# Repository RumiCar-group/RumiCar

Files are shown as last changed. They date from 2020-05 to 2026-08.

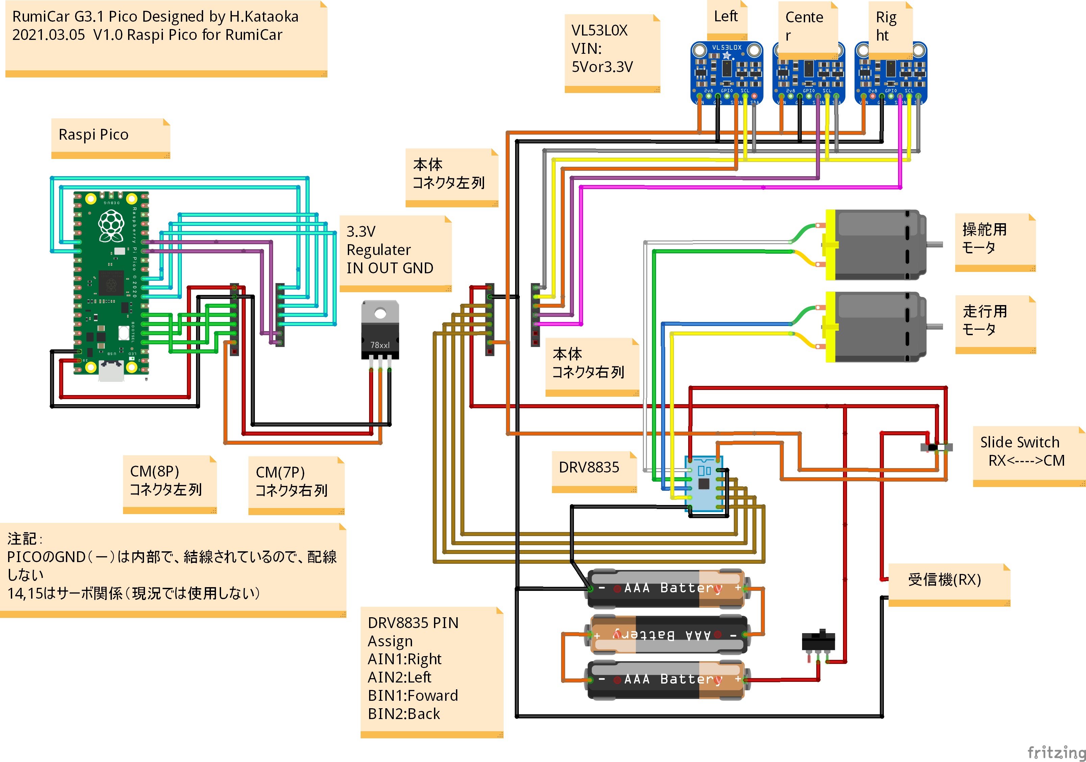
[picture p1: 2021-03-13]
CM PCB/Kataoka san CM/RasPi/結線図RasPiPICO.jpg

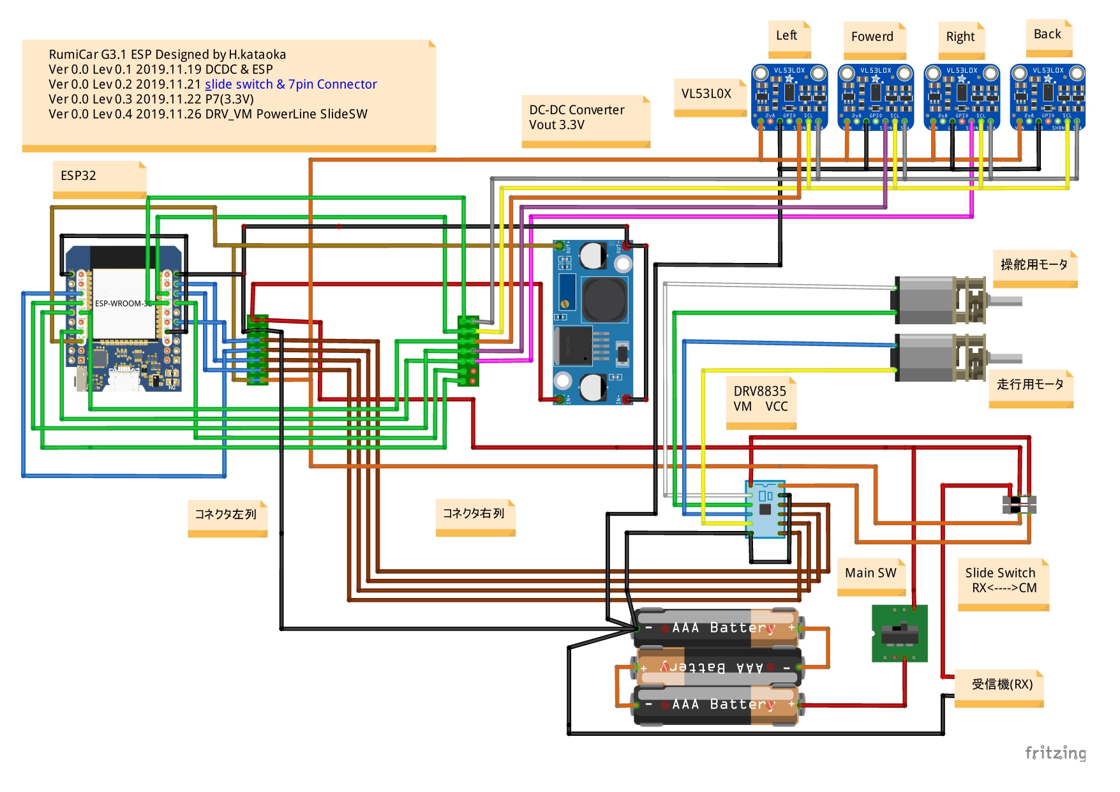
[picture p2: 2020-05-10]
開発用資料/結線図/結線図RumiCarG3.1_ESP32.jpg

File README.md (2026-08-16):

RumiCarロゴ
RumiCar写真

# RumiCar

> [!IMPORTANT]
> ## 📢 お知らせ / Announcement
>
> **Arduino IDE用のRumiCarライブラリは、Arduino公式のLibrary Managerに登録されました。**
>
> インストール手順（Arduino IDE 内で完結します）:
>
> 1. Arduino IDEのメニューから「スケッチ」→「ライブラリをインクルード」→「ライブラリを管理...」を開く
> 2. 検索ボックスに `RumiCar` と入力
> 3. 表示された `RumiCar` を選び「インストール」をクリック
> 4. 依存ライブラリ（VL53L0X）のインストール確認が表示されたら「Install all」を選択
>
> ライブラリのソースコード（参考）: [RumiCar-group/RumiCar-lib](https://github.com/RumiCar-group/RumiCar-lib)
>
> このリポジトリ内にあった `ArduinoAndESP32/Libraries/` 配下の旧ライブラリ（`.zip` と `RumiCar/` フォルダ）は**削除しました**。古い資料に残る「RumiCar.zip を選択」という手順はもう使えません。上記の Library Manager をご利用ください。
>
> ---
>
> **The RumiCar Arduino library has been published to the Arduino Library Manager.**
>
> Installation steps (all done inside Arduino IDE):
>
> 1. Open **Sketch → Include Library → Manage Libraries...** in Arduino IDE
> 2. Type `RumiCar` in the search box
> 3. Click **Install** on the `RumiCar` entry
> 4. When prompted to install the dependency (VL53L0X), choose **Install all**
>
> Library source code (for reference): [RumiCar-group/RumiCar-lib](https://github.com/RumiCar-group/RumiCar-lib)
>
> The local copy that used to be under `ArduinoAndESP32/Libraries/` **has been removed**. Older materials may still say "select RumiCar.zip" — that procedure no longer works; please use the Library Manager above.

**日本語** | [English (README.en.md)](README.en.md)

コンピュータモジュールの種類によりプログラムや使用コンピュータ言語が異なります。
Arduino Nano と ESP32 の場合はフォルダArduinoAndESP32をお使いください。
Raspberry Pi Zero W の場合はフォルダRasPiをお使いください。Raspiはコンピュータ言語はPythonです。

画像はYouTubeへのリンクです。クリックしてご覧ください。

- [RumiCar紹介動画](https://youtu.be/DxaY2eCzJzo)
- [衝突回避](https://youtu.be/95pc_4Wf14U)
- [Part 2 of 2 RumiCar on test course](https://youtu.be/oHujTh9AwAw)
- [車載カメラ視点](https://youtu.be/16kOgLMo-Tg)

RumiCar紹介動画 (https://www.youtube.com/watch?v=DxaY2eCzJzo "RumiCar紹介動画")
RumiCar衝突回避動画 (https://youtu.be/95pc_4Wf14U "RumiCar衝突回避動画")
RumiCarテスト走行動画 (https://www.youtube.com/watch?v=oHujTh9AwAw "RumiCarテスト走行動画")
RumiCar車載カメラ視点動画 (https://www.youtube.com/watch?v=16kOgLMo-Tg "RumiCar車載カメラ視点動画")
### 関連リポジトリ（RumiCar ファミリー）

<!-- AUTO-REPOS-JA:START -->
<!-- この表は自動生成です。手で編集しないでください(毎日、公開リポジトリ一覧から再生成されます)。
     説明文・表示順の変更は .github リポジトリの profile/repos-meta.json を編集してください。
     This table is auto-generated daily from the org's public repositories.
     Edit profile/repos-meta.json in the .github repository to change descriptions/order. -->
| リポジトリ | 内容 | ★ |
|---|---|---|
| [**RumiCar**](https://github.com/RumiCar-group/RumiCar) | 本体。サンプルプログラム、ハンズオン教材(PDF)、結線図、開発資料、シミュレータ用プログラム/コース | 35 |
| [**RumiCar-Simulator**](https://github.com/RumiCar-group/RumiCar-Simulator) | ブラウザで動く自動運転シミュレータ(インストール不要・実機互換) | - |
| [**RumiCar-PhotoStrip**](https://github.com/RumiCar-group/RumiCar-PhotoStrip) | 通信量にやさしい写真ストリップ(どのサイトでも使える汎用Web部品・MIT) | - |
| [**RumiCar-VideoLoop**](https://github.com/RumiCar-group/RumiCar-VideoLoop) | 動画ダイジェスト小窓(無音ティーザーをランダム連続再生・クリックで本編へ・MIT) | - |
| [**RumiCarRos**](https://github.com/RumiCar-group/RumiCarRos) | ROS 2対応の実装 | 3 |
| [**RumiCar-lib**](https://github.com/RumiCar-group/RumiCar-lib) | Arduinoライブラリのソースコード(導入はArduino IDEのライブラリマネージャから。ここからのダウンロードは不要) | - |
| [**RumiCar-AutoPost-Guide**](https://github.com/RumiCar-group/RumiCar-AutoPost-Guide) | Publish a WordPress post; What's New and the Facebook Page update automatically. A bilingual methods guide (ja/en) — setup, pitfalls, and log-based verification. | - |
| [**RumiCar-ReleaseNotes-Guide**](https://github.com/RumiCar-group/RumiCar-ReleaseNotes-Guide) | Publish a GitHub Release, get paired JA/EN WordPress articles automatically — a methods guide with the reference implementation from rumicar.com | - |
| [**RumiCarEX**](https://github.com/RumiCar-group/RumiCarEX) | 関連プロジェクトのfork(派生車体) | - |
| [**micro-airc**](https://github.com/RumiCar-group/micro-airc) | 関連プロジェクトのfork(AI RCカー) | 1 |
| [**rumicar-duck**](https://github.com/RumiCar-group/rumicar-duck) | 関連プロジェクトのfork(アヒル型走行車) | - |
<!-- AUTO-REPOS-JA:END -->

### フォルダの説明

- [**ArduinoAndESP32**](https://github.com/RumiCar-group/RumiCar/tree/master/ArduinoAndESP32)フォルダ<br>RumiCarのコンピュータモジュール(CM)のArduino Nano版とESP32版用のサンプルプルプグラムです。<br>ハンズオンで使用するプログラムが保存されています。RumiCarハンズ用の資料は[**ハンズオン用テキスト**](https://github.com/RumiCar-group/RumiCar/tree/master/%E3%83%8F%E3%83%B3%E3%82%BA%E3%82%AA%E3%83%B3%E7%94%A8%E3%83%86%E3%82%AD%E3%82%B9%E3%83%88)フォルダの下に保存されていますのでまずそちらを参照ください。

  - **Exercise-1 距離を測ってみよう！**<br>RumiCarには車体の前方に3個のレーザー測距モジュールを搭載しています。レーザー測距モジュールは人体に無害のレーザー光線を対象物に当て、その反射光が戻ってくるまでの***時間***を計測することによって距離を測定します。音速はマッハと呼ばれ時速1000km以上の速度ですが、光の速さはその音速の***88万倍***も速いです。その光が反射して返ってくるまでのとても短い時間を計って距離を計測するなんて凄いですね。
  
    - **Exercise-1.1 中央のセンサで測距しよう！**<br>RumiCarに3個搭載されているレーザー測距モジュールのうちの一つ、中央のセンサーを使って距離を測ってみます。Arduino IDEが持っているシリアルモニタの機能を使い、測定した距離を皆さんのパソコンにリアルタイムで表示します。センサの前に手をかざして手を前後に動かすと、手とセンサの間の距離が変わりますのでシリアルモニタに表示される距離の値もリアルタイムで変化します。
    - **Exercise-1.2 3つのセンサで測距だ！**<br>RumiCarに搭載されている3個のセンサを全部同時に動かしてみましょう。左、中央、右のそれぞれのセンサが測定した距離の値を同時にリアルタイムでパソコンの画面に表示します。
    - **Exercise-1.3 シリアルプロッタを使ってみよう**<br>Arduino IDEにはシリアルプロッタの機能もあります。これはデータを自動でグラフ表示してくれる機能です。プログラムはExercise-1.2と同じものを使いますが測定した距離値がリアルタイムに色分けされてグラフ化表示されます。Exercise-1.2と同じようにセンサの前に手をかざしてグラフが変化するか見てみましょう。どの色のグラフがどのセンサの値を表示しているか確かめましょう。このExerciseではExercise-1.2のプログラムをそのまま使いますので専用のプログラムはありません。
  - **Exercise-2 モータ制御**<br>RumiCarはハンドルを曲げる時と走行する時にモータを使います。RumiCarではCMのコンピュータがプログラムに従って、ハンドルを動かしたりRumiCarが走るためにタイヤを回転させたりします。コンピュータモジュールを使ってRumiCarのモータを動かしてみましょう。
    - **Exercise-2.1 ハンドルを切る**<br>RumiCarの前のタイヤを左右に動かしてみましょう。このプログラムではハンドルを左右に切ってそのまま0.5秒保持します。その動作を繰り返します。つまり、左に切って0.5秒、右に切って0.5秒、また左に切って0.5秒と、ずっと繰り返します。
    - **Exercise-2.2 速度制御**<br>RumiCarの走る速度をコントロールしてみましょう。コンピュータモジュールからの命令によって走行用車輪、すなわち後ろのタイヤを回転させます。タイヤの回転速度を変化させることによりRumiCarの走るスピードを変化させることができます。ここではプログラムを使ってタイヤの回転速度を段階的に変化させます。モータの回転音が変わりますのでタイヤの回転を見るのと同時にモータの音の変化にも気をつけてみてください。
    - **Exercise-2.3 前進と後進**<br>実際の自動車は前に進んだり後ろに下がったりします。RumiCarも同様に前進や後進ができます。プログラムを使ってRumiCarを前進させたり後進させてみましょう。RumiCarを走らせる場所が無い時は、RumiCarを手にしっかり持って後ろのタイヤが前進方向に回転したり、後進方向に回転するのを確認しましょう。
    - **Exercise-2.4 ジグザグ走行**<br>RumiCarをジグザグに走行させてみましょう。ハンドルを左右に切りながら前進します。RumiCarを走らせられる場所が無い場合はRumiCarをしっかり手に持って期待通りの動きになっていることを確認しましょう。
  - **Exercise-3 自律走行基礎**<br>自律走行の基礎としてセンサ等が取得した情報を元に判断してRumiCarを制御してみます。前方の障害物や左右の壁などの距離を測定し、停止したり左右にハンドルを切りながらRumiCarを走行させてみます。
    - **Exercise-3.1 安全に停止する車**<br>前方に障害物を発見して安全に停止する車を考えます。RumiCarが直進中に前方に障害物を発見したら停止し、障害物が無くなったら走行そ再開します。障害物が近づいてきたら、安全のために後進します。あなたの手を障害物と仮定してRumiCarがあなたの手にぶつからずに停止するか試してみましょう。RumiCarが停止中にあなたの手をRumiCarに近づけたら安全確保のためにRumiCarが後進しますか？
    - **Exercise-3.2 市街地を走る車**<br>このExerciseでは実際に走行コースを設置してRumiCarを走らせます。左右の壁や前方の障害物を検知しながらRumiCarが走行します。
- **[ESP32](https://github.com/RumiCar-group/RumiCar/tree/master/ESP32)フォルダ**<br>RumiCarのCMのうち、ESP32はWiFiやBluetoothなどの通信機能を内蔵しています。ここではESP32のBluetooth機能を使ってRumiCarのセンサ測距値を無線で取得して表示させたり、RumiCarをワイヤレスで制御するサンプルプログラムが入っています。
     - **BLEフォルダ**<BR>Bluetooth Low Energy(BLE)での通信。RumiCarのESP32版CMに搭載されているBLEを使ってスマホ(iPhone)と通信してみましょう。3個の測距モジュールでの距離計測値をiPhoneのBLE Scannerとのアプリで表示させています。マルチコネクトが可能なので、個別の機器と接続や切断が不要ですので、一度に複数の機器から1台のRumiCarに接続することができます。展示会などで来場者に各自のスマホからRumiCarに接続してもらい、自分のスマホで計測値を表示させて楽しんでいただくことなどが可能です。
    - **Bluetoothフォルダ**<br>Exercise-1.2はRumiCar ESP32版CM用Bluetoothシリアル通信のサンプルプログラムです。RumiCarをWindows PCとBluetoothで接続してRumiCarのレーザー測距モジュールの測定距離値をパソコンに表示したり、パソコンからコマンドを送ってRumiCarを操作することができます。
      - Windos10とペアリング
      - 設定->デバイス->Bluetoothとその他のデバイス->Bluetoothまたはその他のデバイスを追加する->Bluetooth
      - RumiCar_ESP32を選択
      - デバイスマネージャー->ポート(COMとLPT)で"Bluetooth リンク経由の標準シリアル(COM #)"　を確認する。 #は数字です。　(2個表示される)
      - Arduino IDEの設定でツール->シリアルポート　で、上記COM #に合わせる
      - ESP32が「ケーブルを繋いでいない」のに測距値がシリアルモニタに表示できます。
      - PC側からコマンドを送ってRumiCarをコントロールできます。
      - サンプルプログラムはコマンド「r」、「l」、「f」、「b」に対応しています。それぞれ右、左、前進、後進を0.5秒実行します。コマンドは全て小文字です。 Arduino IDEのシリアルモニタの送信でコマンドを送ります。
      - ケーブル接続が不要なので、走行中に実際の測距データをPC側で取得したり、PC側からコマンドを送ってラジコンのような操作をすることができるようになります。

- **[RasPi](https://github.com/RumiCar-group/RumiCar/tree/master/RasPi)フォルダ**<br>RumiCarのコンピュータモジュールのラズパイ版のサンプルプログラムです。Pythonで記述されています。ラズパイ版CMを使ってRumiCarを動かす場合にお使いください。
  - **Exercise-1 距離を測ってみよう！**
    - **Exercise-1.1 中央のセンサで測距しよう！**
    - **Exercise-1.2 3つのセンサで測距だ！**   
  - **Exercise-2 モータ制御**   
    - **Exercise-2.1 ハンドルを切る**    
    - **Exercise-2.2 速度制御**
    - **Exercise-2.3 前進と後進**
    - **Exercise-2.4 ジグザグ走行**  
   - **Exercise-3 自律走行基礎**
     - **Exercise-3.1 安全に停止する車**   
     - **Exercise-3.2 市街地を走る車**
 - **[ハンズオン用テキスト](https://github.com/RumiCar-group/RumiCar/tree/master/%E3%83%8F%E3%83%B3%E3%82%BA%E3%82%AA%E3%83%B3%E7%94%A8%E3%83%86%E3%82%AD%E3%82%B9%E3%83%88)フォルダ**<br>RumiCarのハンズオン用テキストが保存されているフォルダです。RumiCarの歴史や仕組み、サンプルプログラムを使ってRumiCarを動作させる方法や例が載っています。ハンズオン用テキストはPDF形式で約10MBほどのファイルサイズです。GitHubから直接参照しようとすると表示できないことがあるようです。一旦ダウンロードしていただいてからご覧ください。
- **[教育機関向け追加課題](https://github.com/RumiCar-group/RumiCar/tree/master/%E6%95%99%E8%82%B2%E6%A9%9F%E9%96%A2%E5%90%91%E3%81%91%E8%BF%BD%E5%8A%A0%E8%AA%B2%E9%A1%8C)フォルダ**<br>RumiCarを教材として教育機関にて授業や演習で利用する場合の追加課題です。Rumicarハンズオンの資料はRumiCarの仕組みや構成を学べるように作られています。学生が自ら更に深く考えて課題を克服し、より良いアルゴリズムを開発できるように研究課題の基礎やグループワークに使えるように追加の課題をまとめました。是非ご利用ください。
- **[開発用資料](https://github.com/RumiCar-group/RumiCar/tree/master/%E9%96%8B%E7%99%BA%E7%94%A8%E8%B3%87%E6%96%99)フォルダ**<br>RumiCarの車体やCMを自作する場合の開発用資料です。

  1. RumiCarを自作する場合はまず「RumiCarの作り方」をご覧いただき、RumiCarを作製後、作製したCMとRumiCarが正しく動作できているかの確認のために、「RumiCarの動作確認方法」の内容に従ってご確認ください。是非多くの人たちにオリジナルのRumiCarを作製いただき、RumiCarの世界を楽しんで頂けると嬉しいです<br>1.1 CMの作製においてArduino Nano以外のCM作製のための情報を追加しました。<br>1.2 ステアリングをサーボ化する場合のピンアサイン(13番ピン)を追加しました。
  1. RumiCarを受け取ったり、運送等により故障していないかを確認する場合は「RumiCarの動作確認方法」の内容に従ってRumiCarが正常動作するかご確認ください。
  1. 各CM別のピンアサイン表があります。プログラムの互換性確保のためCMを自作する場合の結線はそれに従ってください。<br>
  - **結線図フォルダ**
    - 結線図(ArduinoNano).jpg<br>RumiCarの基本である、Arduino Nano版CMの結線図です。RumiCarをこれから始める人向け。
    - 結線図(Raspberry Pi Zero W).png<br>ラズパイZero W版CMの結線図です。Pythonを使いたい方、画像認識、AI等挑戦されたい方向け(上級者向け)。
    - 結線図RumiCarG3.1_ESP32.jpg<br>ESP32版CM結線図です。WiFiやBluetooth接続、ニューラルネットワーク(NN)プログラム等に挑戦されたい方向け(上級者向け)。
    - 車体接続結線表.jpg<br>RumiCar車体側の結線図です。車体を自作されたい方は、このインターフェイスに合わせて作製ください。
    - ピンアサインArduino-ESP32-RasPi-Obniz<br>Rumicar車体のインターフェイスと、各CMのArduino nano、ESP32、ラズパイ、Obnizのピンアサインを一つの表にまとめたものです。
  - **RumiCarの作り方**<br>RumiCar車体の開発方法や各種CMの作製方法が掲載されています。RumiCarの自作を考えられている方は、この資料を参考に是非オリジナルのRumiCarを作製してみてください。作製したRumiCarは「RumiCarの動作確認方法.pdf」の内容に従って動作確認ができます。   
  - **RumiCarの動作確認方法**<br>RumiCarを新規に作製した場合や、運送などにより故障が発生していないか、のためにRumiCarが正常に動作するか確認するための手順をまとめた資料です。こちらを参考にRumiCarの動作確認をしましょう。

- **RumiCar Simulator(ブラウザ版シミュレータ)**<br>ブラウザ上で RumiCar の走行プログラムを書いて試せるシミュレータです → [**RumiCar Simulator**](https://www.rumicar.com/simulator/)。実機が無くてもプログラムの動作を確認でき、車種(FF/FR/4WD × ノーマル/ドリフト)ごとの挙動の違いも体験できます。ここで作った Arduino C++ のプログラムは**そのまま実機 RumiCar でも動作**します。ソースコードは [**RumiCar-group/RumiCar-Simulator**](https://github.com/RumiCar-group/RumiCar-Simulator) で公開しています(自分のサーバーで動かす手順も同梱)。
  - **[programs](https://github.com/RumiCar-group/RumiCar/tree/master/programs)フォルダ**<br>シミュレータ用の走行プログラム集です。車種別に最適化した「Fable Racing Line」6種と、その**設計思想・各定数の意味・実車でのチューニング手順**を [programs/README.md](https://github.com/RumiCar-group/RumiCar/tree/master/programs) に解説しています(各 .ino の冒頭にも「なぜこの設定にしたか」を記載)。利用者が改変したプログラムは [programs/community](https://github.com/RumiCar-group/RumiCar/tree/master/programs/community) に別名で投稿でき(プルリクエスト方式)、シミュレータの「🌐 みんなの投稿」から誰でも再利用できます。
  - **[courses](https://github.com/RumiCar-group/RumiCar/tree/master/courses)フォルダ**<br>シミュレータ用のコースデータです。30種のテストコースと、利用者が投稿したコース([courses/community](https://github.com/RumiCar-group/RumiCar/tree/master/courses/community))が入っています。投稿方法は [courses/README.md](https://github.com/RumiCar-group/RumiCar/tree/master/courses) を参照してください。

### ハードウェア構成

RumiCar 車体は、車体前部に **3 基のレーザー測距（ToF）モジュール**（左・中央・右）を搭載し、その測定値をコンピュータモジュール（CM）が処理して、ステアリングと走行モータを制御します。CM は USB ケーブルで PC に接続してプログラムを書き込みます。

CM は用途に応じて複数の選択肢があります。

| CM | 言語 | 主な用途 |
|---|---|---|
| **Arduino Nano** | C++ | 基本構成。これから始める方向け |
| **ESP32** | C++ | Wi-Fi / Bluetooth・BLE 連携、ニューラルネットワーク等（上級者向け） |
| **Raspberry Pi Zero W** | Python | 画像認識・AI 等（上級者向け） |
| **Obniz** | — | ピンアサイン表に対応表を掲載 |

結線図・ピンアサイン表・「RumiCar の作り方」「RumiCar の動作確認方法」は、上の「フォルダの説明」にある[開発用資料フォルダ](https://github.com/RumiCar-group/RumiCar/tree/master/%E9%96%8B%E7%99%BA%E7%94%A8%E8%B3%87%E6%96%99)にあります。自作される場合は、プログラムの互換性確保のため、ピンアサイン表に従って結線してください。

### 参加する（協力者募集）

RumiCar は有志で開発しています。**一緒に RumiCar したい方・企業を募集しています。**

- ソフトウェア（自動運転アルゴリズム、IDE、画像認識、Autoware 導入）
- ハードウェア（車体開発・量産、CM 開発、PCB 設計）
- Website 編集・管理（WordPress）、技術アドバイザー
- 広報（YouTube 動画編集、イベント告知）、イベント運営、資金調達

貢献可能な分野とモチベーションを添えて **info@RumiCar.com** までご連絡ください。各国での開発・教室・トレーニング・カンファレンス開催も計画しており、各国拠点でご協力いただける方を探しています。

  ### その他大事なこと
  - [**RumiCar website**](https://www.rumicar.com)<br>RumiCarのwebisteです。今後このwebisteを発展させたいので、websiteの編集をしてくださる方は是非ご連絡ください!
  - [**RumiCar YouTube**](https://www.youtube.com/channel/UCVg3CBSVBcc_00FdC6q2wDg)<br>RumiCarのYouTubeチャンネルです。RumiCarの紹介動画や各種走行動画、開発途中の各種テストの動画などがアップロードされています。是非チャンネル登録をお願いします。また、動画編集をしてくださる方も是非ご連絡ください。
  - [**RumiCar group**](https://www.facebook.com/groups/rumicar)<br>RumiCarのFaceBookグループです。皆様のご参加をお待ちしてます。
  - [**connpass**](https://rumicar.connpass.com)<br>RumiCarの走行会や開発教室、オンラインセミナーなどイベント告知や参加者募集のページです。RumiCarイベントに参加ご希望の方は是非メンバー登録をお願いいたします。
  - [**RumiCarハンズオン中継の録画**](https://youtu.be/99zH73B8NUo)<br>ALGYANとコラボしたRumiCarイベントのアーカイブです。イベント内でExerciseの解説やデモをしています。

Issue・プルリクエストは**英語でも日本語でも歓迎**します。 / Issues and pull requests are welcome in English or Japanese.

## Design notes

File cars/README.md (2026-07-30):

# cars — 車種カタログ

- `cars/community/*.json` — **利用者が投稿した独自車種** (車種 def 形式)

[RumiCar Simulator](https://www.rumicar.com/simulator/) は起動時に `cars/community/` を読み込み、
車種の選択肢に **「🌐 名前」** として追加します。誰でも選んで走らせ、再利用できます。

組込の6車種 (ノーマル FR/FF/4WD・ドリフト FR/FF/4WD) はシミュレータ本体に入っており、
ここには含まれません。このフォルダは**投稿されたものだけ**が入ります。

## 車種を投稿する (PR)

1. シミュレータの「車種」パネルで「車種を追加」を開き、フォームまたは JSON でパラメータを決める
2. 走らせて納得いくまで調整する
3. 「🌐 共有」ボタンを押す → GitHub の新規ファイル作成画面が JSON 入りで開きます
4. そのままコミットするとプルリクエストが作成されます (書込権限が無い場合は自動で fork されます)
5. マージ後、全利用者の車種一覧に表示されます

## フォーマット

`key` と `name` が必須で、あとは省略すると**ノーマル FR の値で埋まります**。一部だけ指定しても動きます。

```json
{
  "key": "custom_lightweight_fr",
  "name": "軽量ライトウェイトFR (投稿例)",
  "mass": 900,
  "accel": 1.18,
  "os": 0.12,
  "powerOs": 0.34,
  "drift": null
}
```

実例は [`community/example-community-car.json`](community/example-community-car.json) にあります。

### パラメータ

| キー | 範囲 | 意味 |
|---|---|---|
| `mass` | 200〜3000 | 車重(kg)。重いほど旋回でアンダー(慣性)・制動が伸びる |
| `accel` | 0〜3 | 加速の倍率。大きいほど速く目標速度へ |
| `brake` | 0〜3 | 制動の倍率。大きいほど短く止まる |
| `maxSpeed` | 0〜2 | 最高速の倍率 (基準 0.7 m/s に対する比) |
| `spin` | 0〜2 | 発進ホイールスピン量。大きいほど発進で空転し加速が鈍る (FF大/4WD≈0) |
| `yawGain` | 0〜3 | 旋回ヨーの基本倍率 |
| `us` | 0〜2 | 定常アンダーステア量。大きいほど高速で曲がりにくい |
| `os` | 0〜2 | 定常オーバーステア量。大きいほど高速で巻き込む |
| `powerUs` | 0〜2 | アクセルON時に増すアンダー (FF: 前輪が駆動+操舵で飽和) |
| `powerOs` | 0〜2 | アクセルON時に増すオーバー (FR: パワーオーバーステア) |
| `liftOffOs` | 0〜2 | アクセルOFF旋回で増すオーバー (タックイン) |
| `brakeOs` | 0〜2 | 制動中に増すオーバー (前荷重でリアが軽い。FR顕著) |
| `slide` | 0〜1 | 通常時の横滑り量 |
| `drift` | — | ドリフト設定。`null` = 滑らない |

数値はすべて有限数である必要があります (`null` や `NaN` は不正)。範囲外の値は保存時に弾かれます。

### ドリフトさせる場合

`drift` にオブジェクトを与えると、省略した項目はドリフト FR の既定値で埋まります。

```json
{
  "key": "custom_drift_special",
  "name": "投稿ドリフト車",
  "drift": {
    "trigger": "power",
    "grip": 0.85,
    "gain": 6.0,
    "minSp": 0.20,
    "slipYaw": 1.10,
    "slipSlide": 0.90,
    "attack": 8.0,
    "release": 4.0,
    "brakeDrift": false
  }
}
```

| キー | 範囲 | 意味 |
|---|---|---|
| `trigger` | `"power"` / `"liftoff"` | 滑り出す契機。`power` = 踏み過ぎ (FR/4WD)、`liftoff` = 急に抜く (FF) |
| `grip` | 0〜1.5 | この駆動力を超えると滑り出す閾値 |
| `gain` | 0〜12 | 滑りの増え方 |
| `minSp` | 0〜2 | 滑り出しに要する最低速度 |
| `slipYaw` | 0〜3 | 滑走中に増える回頭量 |
| `slipSlide` | 0〜2 | 滑走中の横流れ量 |
| `attack` | 0〜20 | 滑り出しの速さ |
| `release` | 0〜20 | グリップ回復の速さ。大きいほど御しやすい |
| `brakeDrift` | 真偽値 | 制動でもドリフトを誘発するか |

## ルール (ゆるく)

- **上書きせず別名で**追加してください。`key` は組込6種 (`normal_fr` / `normal_ff` / `normal_awd` / `drift_fr` / `drift_ff` / `drift_awd`) と重複させないでください
- 不要になったファイルの**削除は GitHub 上**で行います
- 極端なパラメータ (異常に軽い・速い) は他の投稿と一緒に走らせたとき成立しなくなります。まずシミュレータで走らせて確認してください

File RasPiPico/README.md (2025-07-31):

# Raspberry Pi Pico
The build is using [Arduino-Pico](https://arduino-pico.readthedocs.io/en/latest/).

As name suggests, it allows executing Arduino code on Pico!

## Setup PIO
https://docs.platformio.org/en/latest/core/installation/methods/installer-script.html

## Build
```
pio run
```

## Build, Upload and Run
1. Press BOOTSEL
2. Connect USB
3. Unpress BOOTSEL
4. Run:
```
pio run -t upload
```

## Serial Output
```
pio device monitor
```

## Examples
Please, follow `../ArduinoAndESP32/`

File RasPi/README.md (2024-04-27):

# RumiCar
2020年4月25日(土)に開催された「RumiCarハンズオン中継！自動運転アルゴリズムを楽しく手軽に体感しよう！#2 」で使用されたExerciseのラズパイ版です。

## Setup

If you don't have RasPi monitor and keyboard, please check [Remote Access](docs/RemoteAccess.md).

### SMBus (I2C)
Used for VL53L0X.
```
sudo apt install python3-smbus
sudo raspi-config
# Interface Options -> I2C -> Yes
```

### GPIO
* [pigpio library](http://abyz.me.uk/rpi/pigpio/index.html) 使用
* [pinout](https://pinout.xyz/)

```
sudo apt-get update
sudo apt-get install pigpio python3-pigpio  # python-pigpio - python2 deprecated
sudo systemctl enable --now pigpiod
```

以下主要なGPIOをライブラリサイトより一部抜粋。

| PIN | Note  | GPIO |
| --- | ----- | ---- |
| 1 | 3V3 | |
| 2 | 5V | |
| 3 | SDA | 2 |
| 4 | 5V | |
| 5 | SCL | 3 |
| 6 | GND | |
| 9 | GND | |
| 11  | AIN1  | 17 |
| 12  | BIN1  | 18 |
| 13  | AIN2  | 27 |
| 14  | GND | |
| 15  | SERVO | 22 |
| 16  | SHDN0 | 23 |
| 17  | 3V3 | |
| 18  | SHDN1 | 24 |
| 20  | GND | |
| 22  | SHDN2 | 25 |
| 25  | GND | |
| 30  | GND | |
| 33  | BIN2  | 13 |
| 34  | GND | |
| 37  | SERVO | 26 |
| 39  | GND | |

## Exercises

```
cd ~/RasPi/Exercise-1.1
python Exercise-1.1.py

cd ~/RasPi/Exercise-1.2
python Exercise-1.2.py

# ...
```

## Video Streaming
To enable camera, edit `/boot/firmware/config.txt` (or `/boot/config.txt`):
```
camera_auto_detect=0
start_x=1
```

Check camera specs:
```
sudo apt install v4l-utils
v4l2-ctl --all
```

On robot:
```
sudo apt-get install gstreamer1.0-tools gstreamer1.0-plugins-good

gst-launch-1.0 v4l2src device=/dev/video0 ! video/x-raw, format=YUY2, width=640, height=480, framerate=30/1 ! jpegenc ! rtpjpegpay ! udpsink host=<ubuntu>.local port=1234
```
, where the `<ubuntu>` is hostname of your PC from the same LAN.

On PC:
```
gst-launch-1.0 -v udpsrc port=1234 ! "application/x-rtp, payload=26" ! rtpjpegdepay ! jpegdec ! autovideosink sync=false
```

General camera info:
* https://www.raspberrypi.com/documentation/accessories/camera.html

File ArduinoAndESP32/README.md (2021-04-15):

# Arduino Nano, ESP32版CM
画像はYouTubeへのリンクです。動画ではExerciseをデモンストレーションしています。クリックしてご覧ください。<br>
[YouTube video: 【オンライン開催】RumiCarハンズオン中継！自動運転アルゴリズムを楽しく手軽に体感しよう！](https://youtu.be/99zH73B8NUo)<br>
【オンライン開催】RumiCarハンズオン中継！自動運転アルゴリズムを楽しく手軽に体感しよう！ (http://www.youtube.com/watch?v=99zH73B8NUo)<br><br>
Arduino NanoおよびESP32のCMに対応したRumiCarのExercise集です。

Exercise, Exercise-1.1~3.2については、Arduino IDEのライブラリ設定が必要です。[導入方法](./Libraries/README.md)を参照してください。

Exercise-A2.3やExercise-A3.1など数字の後にAとBが付いているExerciseは上級編です。モーターをゆっくりと回転させたりスムーズに回転させる、難易度が少し高めのプログラムです。イベント中には使いませんが挑戦してみてください。

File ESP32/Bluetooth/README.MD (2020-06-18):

#　Exercise-1.2はRumiCar　ESP32版用Bluetoothシリアル通信のサンプルプログラムです

1. Windos10とペアリング
1.1 設定->デバイス->Bluetoothとその他のデバイス->Bluetoothまたはその他のデバイスを追加する->Bluetooth
1.2 RumiCar_ESP32を選択
1.3 デバイスマネージャー->ポート(COMとLPT)　　で　"Bluetooth リンク経由の標準シリアル(COMn)"　を確認する"n"は数字　(2個表示される)
1.4 Arduino IDEの設定でツール->シリアルポート:　で、上記COMnに合わせる

２.ESP32が「ケーブルをつないでいない」のに測距値がシリアルモニタに表示できます

３.PC側からコマンドを送ってRumiCarをコントロールできます

サンプルプログラムはコマンド「r」、「l」、「f」、「b」に対応、それぞれ右、左、前進、後進を0.5秒実行します。コマンドは全て小文字です。
Arduino IDEのシリアルモニタの送信でコマンドを送ります

ケーブル接続が不要になりますので走行中に実際の測距データをPC側で取得したりPC側からコマンドを送ってラジコンのように操作したり、ができるようになります

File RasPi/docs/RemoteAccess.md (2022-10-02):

# Remote Access

allows using RumiCar without monitor and keyboard.

## Change WiFi with Command Line
This step is needed if Wifi does not work. 

### Easy Way
* Just run RasPi Imager again setting other WiFi.

### Hard Way
[**RasPi Config**](https://www.raspberrypi.com/documentation/computers/configuration.html#using-the-command-line)
* Insert SD card into other linux PC.
* Edit `<SD card mount>/etc/wpa_supplicant/wpa_supplicant.conf`
* Insert SD card back, start the RasPi and check it is connected to WiFi.

### Notes
* The RasPi needs to be in the same LAN as your remote PC. For example, both PC has address `192.168.1.* / 24`.
* Sometimes WiFi can isolate PC from each other, so in this case either disable the isolation or use another WiFi.

## ssh
```
# Remote PC
ssh pi@rcar.local  # <user>@<host>.local
```
On windows, [**Bonjour**](https://support.apple.com/kb/dl999) is needed to use `.local` hostname instead of ip address.

## Copy Sources
```
# Remote PC
scp -r RasPi pi@rcar.local:
```

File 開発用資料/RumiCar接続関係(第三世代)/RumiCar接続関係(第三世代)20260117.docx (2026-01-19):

RumiCarインターフェイス資料（第三世代）

2026年1月17日版

表目次

図目次

# 1. 定義・参考情報

  (1) 電線
    1 電力系　AWG24（最大3.5A）程度
    2 信号系　~~AWG30（最大0.86A）程度~~マルツではAWG28までしか売ってない。AWG28(最大1.2A)
  (2) 電源
    1 車体から供給される電源は基本4.5Vと仮定されて仕様が決められている。これ以外の電圧の車体で利用する場合はCM側の電圧昇降圧機能を鑑みて運用を考えること
  (3) CM
    1 コンピュータモジュールの略。ArduinoやESP32が搭載されRumiCarと接続して使われる

# 2. 注意

(1) DRV8835の信号線はDRV8835のVCCが上限になる。信号線接続時は接続コンピュータの信号最大値に気を付けること
(2) VL53L0Xの信号最大電圧及びI2C信号電圧にも気を付けること。基本的にVL53L0XのVCCと合わせる。
(3) Arduino系のPWMピンは3,5,6,9,10,11の６本。タイマ0のみが960Hz、Servoライブライを使うとタイマ1（9,10番ピン）のPWMは使えなくなる。これより操舵を3,11番(タイマ2)、走行を5,6番(タイマ0)、サーボを9,10番(タイマ1)とするのが良いだろう。

表 　ArduinoタイマとPWM

タイマ | ピン | 周波数
タイマ0 | ５、６ | 980Hz
タイマ１ | ９、１０ | 490Hz
タイマ２ | ３、１１ | 490Hz

(4) Arduino NanoはツールメニューからプロセッサとしてATmega328p(Old　bootloader)を指定すること。そうしないと書き込めない（2018年11月26日追記）

# 3. 接続

(1) 車体インターフェイス表記:Pnn 例:P10はSHDN0の意味
(2) A-D9等はArduinoのディジタル9番ピンの意味。E-xxx表記はESP32のピンの意味
(3) VL53L0X(レーザー測距モジュール)
1 1モジュール当たりに電源２本、I2C ２本とアドレス設定用１本（SHDN）が必要、つまり1モジュール当たり5本、ただし電源と信号線2本は共通で良い
2 3モジュールの場合は電源2本、I2C 2本、SHDNモジュール数分(3本)の7本必要
3 動作電圧は3.3Vから5.0V、自動車本体は4.5V供給可能であるが信号線最大電圧に合わせる必要があるのでP7(Arduino　V5、ESP３２　3.3V)から電源供給することにする
(4) UART(シリアル通信)
1 Arduino

ハードウエアシリアルは１個しかない。通常その１個はPCでのシリアルモニタに使う。そのため他のモジュール(例えばVR3等)とシリアル通信をする場合はソフトシリアルを使う。シリアル通信用ピンは空いているピンをソフトウエア的に設定可能。例えばA6、A7やD7、D8などが使える。もちろんシリアルモニタを使わない、PCと接続しない使い方であればシリアル0が使える。

2 ESP32

ハードウエアシリアルは３個ある。シリアル0はPCと接続、シリアルモニタで使う。シリアル1は内部使用のため使えない。従ってシリアル2を使う。ピンはGPIO16と17を使う。

表 1　ESP32のUART

UART | RX | TX | 備考
UART0 | GPIO3 | GPIO1 | USB書き込みで使用、使用推奨しない
UART1 | GPIO9 | GPIO10 | 通常使用不可
UART2 | GPIO16 | GPIO17 | 今回採用

(5) 電源の考え方

ArduinoはUSB経由での電源供給は5Vになる。仕様では７Vから12VをVINに供給することになっている。ArduinoはVINの電源から内蔵レギュレータにより自分で内部電源用5Vを生成している。現在Arduino系CMの電源には昇圧型可変電圧型DC-DCコンバータ(MT3608等)を使っている。可変電圧型DC-DCコンバータで正確に3.3Vや5Vを生成しにくいため仕様に従ってVINに7.2V程度を供給している。DRV8835やVL53L0Xの電源供給はArduinoの供給能に頼っている。Arduinoは1ピン当たり最大40mAで全体で100mA供給できる。ESP32は供給可能な電力がもっと少ないのでESP32などから電源供給させずに3.3V固定型DC-DCコンバータなどを使いESP32への電源供給とともにP7(DRV8835やVL53L0Xへの電源供給ピン)へも並列で電源供給すると良いだろう。電圧固定型DC-DCコンバータであれば例えば5V供給するのであればArduinoもVINではなく5Vラインに直接電源供給できる。

(6) I2C通信

通常I2C通信の機器は機器毎に固有のアドレスを持たせてそのアドレスに対して通信する。逆に言うと複数の機器を同時に使う場合、それらの機器のアドレスは重複せずに一意である必要がある。今回VL53L0Xを複数使うがVL53L0Xは工場出荷時に全てに同じアドレスが設定されている。複数使うときにはアドレスの再設定が必要となる。VL53L0Xの仕様としてSHDN(シャットダウン)後にアドレスを送るとその機器のアドレスがその送ったアドレスに書き換わる機能がある。今回その機能を使って3個のVL53L0Xを使い分けることにした。書き換えられた新アドレスは機器に記憶されないのでVL53L0X起動時に常にCMから各VL53L0Xのアドレスを書き換えて使用するロジックを組む必要がある。

(7) CMモジュール(Arduino等側)と車体側の接続
1 EX-IF（車体インターフェイス(車体側、図の上方が進行方向(前方))）

表 2　第三世代　車体-CM接続インターフェイス(EX-IF)(旧表記)

I/O | 用途 | ピン番号 | | 用途 | I/O
O | 電源(4.5V) | 1 | 8 | SDA:E-GPIO21 | I
O | GND | 2 | 9 | SCL:E-GPIO22 | I
I | AIN1:右折側:A3; E-GPIO04 | 3 | 10 | SHDN0(左):E-GPIO19 | I
I | AIN2:左折側:A11: E-GPIO26 | 4 | 11 | SHDN1(中):E-GPIO18 | I
I | BIN1:前進側:A5: E-GPIO27 | 5 | 12 | SHDN2(右):E-GPIO05 | I
I | BIN2:後進側:A6: E-GPIO25 | 6 | 13 | SERVO(操舵)用A9番ピン E-GPIO32 | I
I | 信号最大電圧及び電力供給(通常コンピュータのVCC)(5Vまたは3.3V)VL53L0XとDRV8835のVCCへ | 7 | 14 | SERVO用A10番ピン E-GPIO33 | I
| 誤挿入防止用のダミーピン (接続先は無し) | 7.5

P7はCM(ArduinoやESP32)の動作電圧と同じ電圧の「電源用」として車体側に供給すること。車体側ではP7を電源としてVL53L0XやDRV8835が動く。

P7はCM側がArduino系の場合は5Vラインに接続する。CM側がESP32の場合はDCDCコンバータの3.3V電源に直接接続する(ESP32の3.3Vラインには接続しない)

~~表~~ ~~3~~~~車体-CM接続インターフェイス~~~~(縦表記)~~

~~ピン番号~~ | ~~I/O~~ | ~~用途~~ | ~~CM側接続~~~~先(ピン番号等)~~
| | | ~~Arduino~~~~(A/D)~~ | ~~ESP32~~~~(GPIOピン番号)~~
~~1~~ | ~~O~~ | ~~電源(4.5V)~~ | ~~DCDCコンバータの入力~~
~~2~~ | ~~O~~ | ~~GND~~
~~3~~ | ~~I~~ | ~~AIN1:右折側~~ | ~~3~~~~(D3)~~ | ~~04~~
~~4~~ | ~~I~~ | ~~AIN2:左折側~~ | ~~11~~~~(D11)~~ | ~~26~~
~~5~~ | ~~I~~ | ~~BIN1:前進側~~ | ~~5~~~~(D5)~~ | ~~27~~
~~6~~ | ~~I~~ | ~~BIN2:後進側~~ | ~~6~~~~(D6)~~ | ~~25~~
~~7~~ | ~~I~~ | ~~VL53L0XとDRV8835のVCCへ~~ | ~~5V~~~~出力~~~~ライン~~ | ~~(~~~~ESP32ではなく~~~~)~~~~DCDCコンバータの3.3V出力へ~~
~~7.5~~ | | ~~誤挿入防止用のダミーピン~~ ~~(接続先は無し)~~
~~8~~ | ~~I~~ | ~~SDA~~ | ~~18~~~~(A4)~~ | ~~21~~
~~9~~ | ~~I~~ | ~~SCL~~ | ~~19~~~~(A5)~~ | ~~22~~
~~10~~ | ~~I~~ | ~~SHDN0(左)~~ | ~~14~~~~(A0)~~ | ~~19~~
~~11~~ | ~~I~~ | ~~SHDN1(中)~~ | ~~15~~~~(A1)~~ | ~~18~~
~~12~~ | ~~I~~ | ~~SHDN2(右)~~ | ~~16~~~~(A2)~~ | ~~05~~
~~13~~ | ~~I~~ | ~~SERVO用~~ | ~~9(D~~~~9~~~~)~~ | ~~32~~
~~14~~ | ~~I~~ | ~~SERVO~~ | ~~10(D~~~~10~~~~)~~ | ~~33~~

表４は表１２に変更。表１２を参照。

I/Oの表記は車体側から見た表記。例えばP1はO、つまり出力になっている。これは車体側の電源4.5VをCM(コンピュータモジュール)側に供給するから車体側から見れば出力になる。

第三世代は赤外線測距モジュール利用は想定せずレーザー測距モジュールを想定する。

なおP7は今回「I」に変更した。理由としてモータドライバの信号線入力（AIN1など）が最大値でVCCとなっているため。モータドライバに直接乾電池からの電源供給すると4.5Vになる。モータドライバ自体は問題なく動くが信号入力電圧上限が4.5VとなってしまいArduinoの信号出力だと5Vが掛かってしまいオーバーする。ESP32だと3.3Vであるので上限自体はオーバーしないが半端な電圧となる。従ってモータドライバのVCCとCMのVCC（Arduino(5V)やESP32(3.3V)）を合わせるためCM側のコンピュータのVCCと同等の基本電圧を供給することとする。

~~8号車のP1は9V~~

(8) DVR8835(モータドライバ)

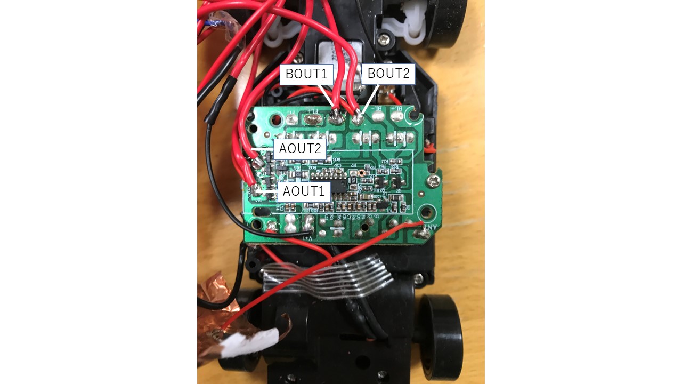
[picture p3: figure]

図 1　24型結線図

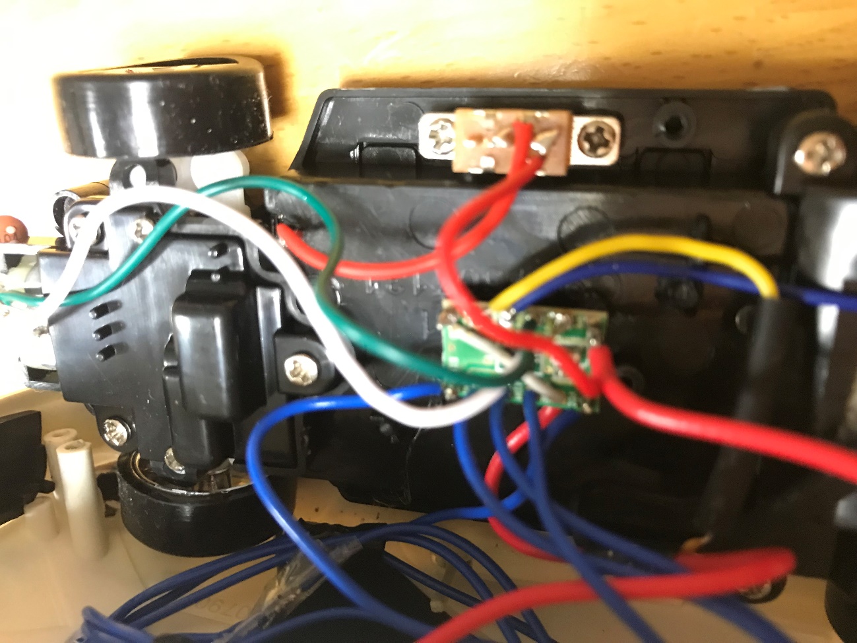
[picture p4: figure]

図 2　32型結線図

24型(型番24-1-xx)はラジコン受信機を残しスイッチでラジコンとコンピュータコントロールを切り替えられるようにした。32型(型番 32-1-xx)は配線取り回しが厳しいのでラジコン受信機は撤去しコンピュータコントロールのみとした。

表 4　32型DRV8835結線図

接続先 | 端子(左/右) | | 接続先
本体電源(スイッチ経由) | VM | VCC | P7
操舵モータ白線 | AOUT1 | MODE | グランドへ
操舵モータ緑線 | AOUT2 | AIN1 | P3
走行モータ青線 | BOUT1 | AIN2 | P4
走行モータ黄線 | BOUT2 | BIN1 | P5
グランド(乾電池マイナス側へ) | GND | BIN2 | P6

1 型番32-1-xxタイプの第二パラメータが「1」のモデルはサーボモータを内蔵していないのでP13とP14は接続なし
2 電源は本体スイッチ経由の「＋」電源を指す。

接続先

      1. 本体スイッチ経由の「+」電源
      2. DRV8835のVM
      3. 車体-CMのP1
3 グランドは本体電池端子の「-」側に接続する

接続先

      4. 本単電池端子「-」
      5. DRV8835のグランド
      6. DRV8835のMODEへ
      7. 車体-CMのP2
      8. 各VL53L0XのGND
(9) VL53L0Xの結線
1 VIN、GND、SCL、SDAは３個の素子をそれぞれまとめて１本にして良い。例えば各VL53L0XのSCL３本をまとめて１本として、P9に接続する。個別に接続する必要があるのはシャットダウンライン（モジュールにより表記がことなるがSHDNやXSHUT等の表記になる）のみである。GPIOは使わない(結線せず)

接続先

      9. 3本まとめたVINはP7へ
      10. 3本まとめたGNDはグランドへ(P2や乾電池端子「-」)
      11. 3本まとめたSDAはP8へ
      12. 3本まとめたSCLはP９へ
      13. 左VL53L0XのSHDNはP10へ
      14. 真ん中のVL53L0XのSHDNはP11へ
      15. 右のVL53L0XのSHDNはP12へ
(10) BMX055の結線
1 JP6をショート(５V電源)
2 JP4とJP5をショート（I2C内部プルアップ有効）

第三世代はモータドライバは本体に搭載することにした。理由はコンピュータのVCCと動作電圧を合わせた方が良いからである。

またDRV８８３５は超低消費電力（通常時450μA、最大2000μA（2mA））となっておりArduinoの5V端子（40mA）でも十分動作可能である。

動作電圧は７から12Vで信号電圧は5V。

ESP32は動作電圧3.3V（VCC）と信号電圧が同じ。動作電圧と信号電圧が同じ場合はDRV8835のVCCはコンピュータと同じ電源から取ればよい。問題になるのはコンピュータの動作電圧と信号電圧が異なる場合、この場合はコンピュータ（例えばArduino）より5Vを電源供給する。

また測距モジュールも同じSPRESENSEはI2C信号が1.8VなのでI2Cコンバータで1.8Vと5Vを接続することにする。

表 5　Arduino nano(USB端子を下とした図)

接続先 | Arduinoピン | | 接続先
| TX1 | VIN | 電源(DC-DCコンバータからの出力、7.5V)
| RX0 | GND | グランド
| RST | RST
P2 | GND | 5V | P7
| D2 | A7
P3(AIN1) | D3[3] | A6
| D4 | A5[19] | P9(SCL)
P5(BIN1) | D5[5] | A4[18] | P8(SDA)
P6(BIN2) | D6[6] | A3
| D7 | A2[16] | P12(SHDN2)
| D8 | A1[15] | P11(SHDN1)
P13(サーボ) | D9[9] | A0[14] | P10(SHDN0)
P14(サーボ) | D10[10] | REF
P4(AIN2) | D11[11] | 3V3
| D12 | D13

Anはアナログピン、Dnはディジタルピン、[n]は物理ピン

通常はVINに7.2V程度を供給しArduinoの内蔵レギュレータ経由でArduino自身に5V電圧を生成させる構成とする(標準構成)。VL53L0XやDRV8835はArduinoやESP32の生成された5Vや3.3Vの供給可能電力で動ける。ただしこれらCM上に他のこれらより消費電力が多そうなモジュールを搭載する場合（例えばVR3）はArduinoやESP32の生成電力では足りない可能性があるのでその場合はArduinoもVINではなく直接5Vや3.3VにDC-DCコンバータ経由で供給する構成にする。DC-DCコンバータより並列でArduino等やモジュールに電源供給する。理由として7.2Vと５V(や3.3V)の2系統の電源を用意するのは回路が複雑になるから避けるためである。特にESP32では直接3,3Vを供給した方が手っ取り早い。

3 ESP32（Devkit）のPWM関係情報

ESP32自体はPWM用に16チャンネルある。

そのうちDevkitなどが内部で使用済で使えないピンがある。

表 6　ESP32/ESP32DevKit　PWM関係ピンアサイン

ESP32 | | ESP32Devkit | 備考・説明
アナログピン番号 | GPIO番号 | 使用不可理由
A0 | 36(使用不可)
A3 | 39(使用不可)
A4 | 32 | | サーボで使用(9番相当)
A5 | 33 | | サーボで使用(10番相当)
A6 | 34(使用不可)
A7 | 35(使用不可)
A10 | 4 | | AIN1とする
A11 | 0 | ブート時使用
A12 | 2 | ブート時使用
A13 | 15 | U0TXDデバッグ用
A14 | 13 | 使用不可(秋月)
A15 | 12 | LDO電圧設定用
A16 | 14
A17 | 27 | | BIN1とする
A18 | 25 | | BIN2とする
A19 | 26 | | AIN2とする

表 7　ESP32DevKit接続図(USB端子を下とした図)

接続先 | ESP32PIN | | 接続先
電源入力 | 3.3V | GND | P2
| EN | GPIO23
出力には使えない | GPIO36 | GPIO22 | P9(SCL)
| GPIO39 | GPIO01 | UART通信用 通常は使わないこと
| GPIO34 | GPIO03
| GPIO35 | GPIO21 | P8(SDA)
P13(SERVO用) | GPIO32 | GND
P14(SERVO用) | GPIO33 | GPIO19 | P10(SHDN0)
P6(BIN2) | GPIO25 | GPIO18 | P11(SHDN1)
P4(AIN2) | GPIO26 | GPIO05 | P12(SHDN2)
P5(BIN1) | GPIO27 | GPIO17 | UART2TX(VR3へ)
| GPIO14 | GPIO16 | UART2RX(VR3へ)
LDO電圧設定用 | GPIO12 | GPIO04 | P3(AIN1)
| GND | GPIO00 | ブート時使用される
使用不可(秋月Webより) | GPIO13 | GPIO02
| GPIO09 | GPIO15 | U0TXDデバッグ用
| GPIO10 | GPIO08
| GPIO11 | GPIO07
| 5V | GPIO06

斜体ゴシックのピンは内部で使用されているため利用禁止

（参考：過去情報）ESP32電源用に三端子レギュレータシャープ製PQ3RD23を採用。３、４号車の三端子レギュレータは東芝製TA48033Sを使用していた。これはArduinoの電源ではなくシャープ製赤外線測距モジュールGP2Y0E02Aが3.3V動作であったため採用していたがTA48033Sは最大1Aまでしか対応できない。そこでより容量の大きい三端子レギュレータを探して採用した。PQ3RD23は最大２Aまで対応可能。ESP32は最大消費電力1.5A程度とのことで容量的には範囲内。ちなみに１、２号車のシャープ製赤外線測距モジュールの電源電圧は5V。

レーザー測距モジュールVL53L0Xの電源は3.3Vから5.0V、ただしDRV8835は乾電池から電源は取れるものの信号線の最大入力がVCCとなっているのでCM側のVCCと電圧を合わせる必要があるからP7から電源を取る。

なお現在は三端子レギュレータではなくDC-DCコンバータで電源生成。

第二世代ではモータドライバはCM側に搭載していた。

IN-IFは廃止

9号車のスイッチ部分。

進行方向左がオン（左と中が導通）

左側に電源からの9Vが供給されている。

オンの時、真ん中下側に9V供給される。

(11) ラジコン切替スイッチ

切り替えスイッチは、下から見て左がCM、右がMC

センサは左が０、真ん中が１、右が２とする。

DRVのVMへ

P1へ

表 8　VL530LXとDRV8835仕様

| GY-VL530XV2 (中国製) | VL53L0X (ストロベリーリナックス製) | DRV8835
電源 | VIN:2.6-5.5V | VDD:3.3-5.0v | Vcc:2-7V
信号線電圧 | SDA/SDC Low=0,HIGH=VIN | 同左 | Vin:最大がVcc
VM | | | 0-7V
その他 | VDDは直接の電源、通常はVCCを使うこと
消費電流 | 10mA(最大40mA) | 同左 | 2mA
測定不能時値 | 8190 | 0

表 9　CM用コンピュータ仕様

| Arduino Nano | ESP32 | RasPiZero | PasPi PICO | Obniz
電源 | 7-12V VINへ | 2.2-3.6V(3V3へ入力の場合) 3.7-6.0V(VINへ入力の場合) | 5V(2番ピンまたは4番ピン) | 39番ピン(VSYS) 1.8-5.5V | ５V 基板裏側
内部動作 | 5V | 3.3V | 3.3V
I/Oピン電圧 | 5V | 3.3V | 3.3V | 3.3V | 5V(電圧選択可能)
I/Oピン電力供給能 | ~~40mA~~ ~~全体で100mA~~ 800mA | 最大12mA | 16mA 全体で50mA | 300mA以下 | 5Vモードで1A
消費電力(電流) | 65mA | WiFi時160-260mA | 125mA WiFi時270mA | 5V給電時95mA程度 | 平均170mA(WiFi不使用時)
USBコネクタ | ミニB | マイクロB | マイクロB | マイクロB
PWM | 6本 | 4本 | ハード2本 | 16本 | ６本
推奨電圧変換 | MT3608系 | PQ3RD23 | MT3608系 またはTPS63020 | ~~PQ3RD23またはTPS63020~~ 入力電圧が1.8V-5.5Vなので車体側電圧が3Vや4.5VであればDCDC不要で直接供給する | MT3608系 またはTPS63020
I/O用電圧 | | | PQ3RD23 またはSOT-23AP7333 | （不要）

Nanoの5V出力800mA(0.8A)については下記の公式ページ参照

https://docs.arduino.cc/learn/electronics/power-pins/

| Spresense
電源 | 5V BtoBの2番と4番ピンへ
内部動作
I/Oピン電圧 | 1.8V
I/Oピン電力供給能 | 6mA
消費電力 | 500mA
I2C電圧 | 1.8V
USBコネクタ | マイクロB

表 10　DC-DCコンバータ仕様

コンバータ | XL6009使用 | LM2577使用 | LM2596 | MT3608 | PQ3RD23 (三端子レギュレータ)
昇降圧タイプ | 昇降圧 | 昇降圧 | 降圧 | 昇圧 | 降圧
入力電圧(V) | 3.8-32 | 3.3-35 | 4-35 | 2-24 | ～20V
出力電圧(V) | 1.25-35 | 1.25-30 | 1.23-30 | 最大28 | 3.3V
出力など | 入力最高3A | 最大2A | 2A(ヒートシンク時3A) | 最大2A出力 | 最大出力2A
入出力絶縁 | 非絶縁 | 不明 | 非絶縁 | 不明
備考 | | | | | 入出力電圧差0.5Vで良い

コンバータ | TPS63000 | TPS63070 | TPS63020
昇降圧タイプ | 昇降圧 | 昇降圧 | 昇降圧
入力電圧(V) | 1.8-5.5 | 2-16 | 1.8-5.5
出力電圧(V) | 3.3か5の切り替え | 2.5-9 | 3.3か5の切り替え
出力など | 入力:1.8A 出力:3.3V降圧時1.2A | 昇降圧とも2A | 昇圧２A 降圧3A
入出力絶縁 | 不明 | 不明

# 4. CM接続

(1) CM
1 CM3-AN系
1. DC-DCコンバータの入力と出力のGNDを接続する
2. DC-DCコンバータの入力側に4.5V直流電源(乾電池直列3本等)を接続し出力側の電圧をテスタ等で計測する
3. 可変ボリュームを回して出力が7.2V程度に調整する
4. ホットメルトグルー等でボリュームを固定
5. これらを台数分作成
6. 左側用8ピンソケットと右側用7ピンソケットを用意。8ピンヘッダと7ピンヘッダを刺す。その状態でD型基盤をはんだ付け開始する
7. モジュールの基盤への取り付けは通常のピンヘッダで良い。細ピンヘッダを使う必要はない
8. 表2及び表4を参考にして配線する。基本はP1からの電源をDC-DCコンバータの入力に接続し、DC-DCコンバータの出力をArduinoのVINに接続する。その後は表3に従い結線する。グランドは各モジュール全部共通接続
2 CM3-AN系動作確認方法
1. 車体に電池を入れたものを用意する。車体側のスイッチは「この時点ではOFFとすること」
2. 車体にCMを接続しUSBケーブルでPCに接続する
3. PC側の接続COMポート番号をデバイスマネージャーで確認する。接続されるCOMポート番号は都度変わるので接続都度確認した方が良い
4. Arduino IDEを立ち上げる。
        (1) ボードはArduino nano
        (2) ブートローダは「同oldブートローダ」
        (3) ポート設定はデバイスマネージャーで確認したCMモジュールが接続されているポートに設定
5. 各接続チェック用プログラム「CarbodyhealthCheckxxxxxxxx」をロード。「xxxxxxxx」は日付表示であり、基本的には最新の日付のものを使うこと
6. このプログラムはVL530LXとのI2C通信や操舵・走行関係の結線が正しく行われているか確認するためのものである
7. Arduino IDEのシリアルコンソールを開いておく
8. プログラムをコンパイルしCMへロードする
9. CMへのプログラムロードが正常終了すると自動的にプログラムが実行されシリアルコンソールへ各３個のVL53L0Xの測距値がそれぞれ表示されるので各センサ(VL530LX)に対して測距対象（例えば手など）を動かしてシリアルモニタ上に表示される測定結果が正しいか目視で確認する。これによりVL530LXに関連するI2C接続の正確性の確認ができる。VL53L0XへはArduinoから電源供給されるので車体の本体スイッチがOFFでもArduinoへ電源供給(例えばPCから)されていればVL53L0Xは稼働できるのでこのような事が可能になる
10. 次にPCと接続しているUSBケーブルを抜く。CMへの電源供給がストップしCMは停止する
11. ここで「OFFになっている車体側スイッチをONにする」
12. 車体側からCMへの電源供給が開始されるのでCMが再び起動する
13. プログラムは、左右のそれぞれの操舵と短く走行用車輪をそれぞれ前後に回転させる。これら動作が確認できたら操舵・走行関係の接続の正確性の確認ができたといえる
14. Arduino　IDEのクローズや本体電源スイッチをOFFにし、終了
3 RumiCar32-1系製作方法
1. 本体を分解し、ラジコン受信機とアンテナを撤去
2. 残す配線や必要な端子は、各モータの線(合計4本)と本体電源スイッチ経由の「+」電源、グランド用の乾電池端子「-」のみ
3. VL53L0Xの配線用にボンネットにドリルで穴を開ける。ドリルで開け、リーマで広げ、穴の縁をカッター等でなめバリを取る

https://www.raspberrypi.org/documentation/usage/gpio/

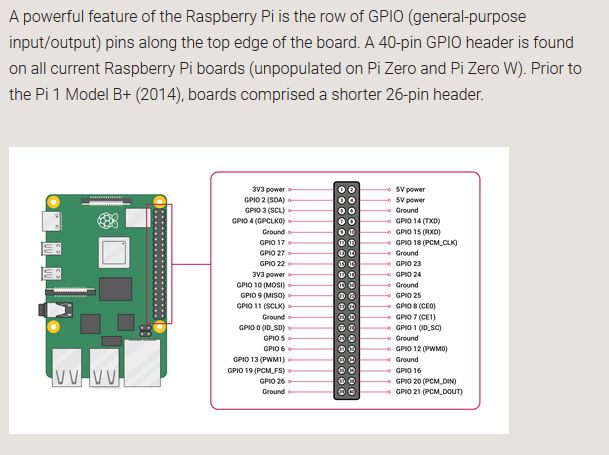
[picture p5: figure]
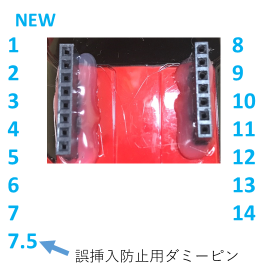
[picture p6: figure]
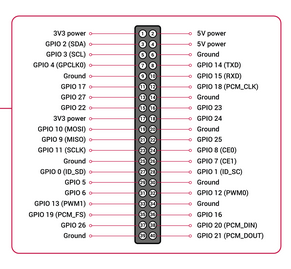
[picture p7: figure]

図 4 RumiCar インターフェイス

表 11　CM接続インターフェイス

| I/O | 用途 | | CM側接続先(ピン番号等) | | Raspberry Pi Zero W | Pico | Obniz | SPRESENSE
| | | | Arduino(A/D) | ESP32(GPIOピン番号) | RasPi ピン番号(GPIO番号)
1 | O | 電源(4.5V) | | DCDCコンバータの入力
| | | | 5V | 3.3V | 5V | 3.3V(1.8から5.5) | 5V
2 | O | | GND
3 | I | AIN1:右折側 | | 3(D3) | 04 | 11(17) | 27(21) | io0 | 39(D06)
4 | I | AIN2:左折側 | | 11(D11) | 26 | 13(27) | 29(22) | io1 | 41(D05)
5 | I | BIN1:前進側 | | 5(D5) | 27 | 12(18)PWM0 (注釈参照) | 31(26) | io2 | 31(D09)
6 | I | BIN2:後進側 | | 6(D6) | 25 | 33(13)PWM1 | 32(27) | io3 | 45(D03)
7 | I | VL53L0XとDRV8835のVCCへ | | 5V出力ライン | (ESP32ではなく)DCDCコンバータの3.3V出力へ | 3.3V出力のDCDCコンバータの出力へ | 36(3V3) | DCDCコンバータの出力(5V)へ
7.5 | | 誤挿入防止用のダミーピン (接続先は無し)
8 | I | SDA | | 18(A4) | 21 | 3(2) | 16(12) | io4 | 21(D14)
9 | I | SCL | | 19(A5) | 22 | 5(3) | 17(13) | io5 | 19(D15)
10 | I | SHDN0(左) | | 14(A0) | 19 | 16(23) | 11(8) | io6 | 28(D02)
11 | I | SHDN1(中) | | 15(A1) | 18 | 18(24) | 10(7) | io7 | 50(D07)
12 | I | SHDN2(右) | | 16(A2) | 05 | 22(25) | 9(6) | io8 | 60(D41)
13 | I | SERVO(操舵)用 | | 9(D9) | 32 | 15(22) | 7(5) | io9 | D08
14 | I | SERVO用 | | 10(D10) | 33 | 37(26) | 6(4) | io10 | D04
ボードの電源 | | | | | 2 | | 39(VSYS)

(注釈)RaspZeroの5番ピンは既に多く出回っているPCB基板のものに合わせ12(18)とする。2026年1月17日

表 12　I2Cアドレス

センサ | | | アドレス | 設定方法
VL53L0X (レーザ測距モジュール) | Sensor0 | 左 | 0x20 | ソフトウエアにより起動時に変更処理実行
| Senseo1 | 中央 | 0x21
| Sensor2 | 右 | 0x22
| Sensor3 | 後部 | 0x52 | 固定値(初期値)
BMX０５５ (9軸センサ) | 加速度 | | 0x19 | 基板上でジャンパ設定
| ジャイロ | | 0x69
| 磁気 | | 0x13

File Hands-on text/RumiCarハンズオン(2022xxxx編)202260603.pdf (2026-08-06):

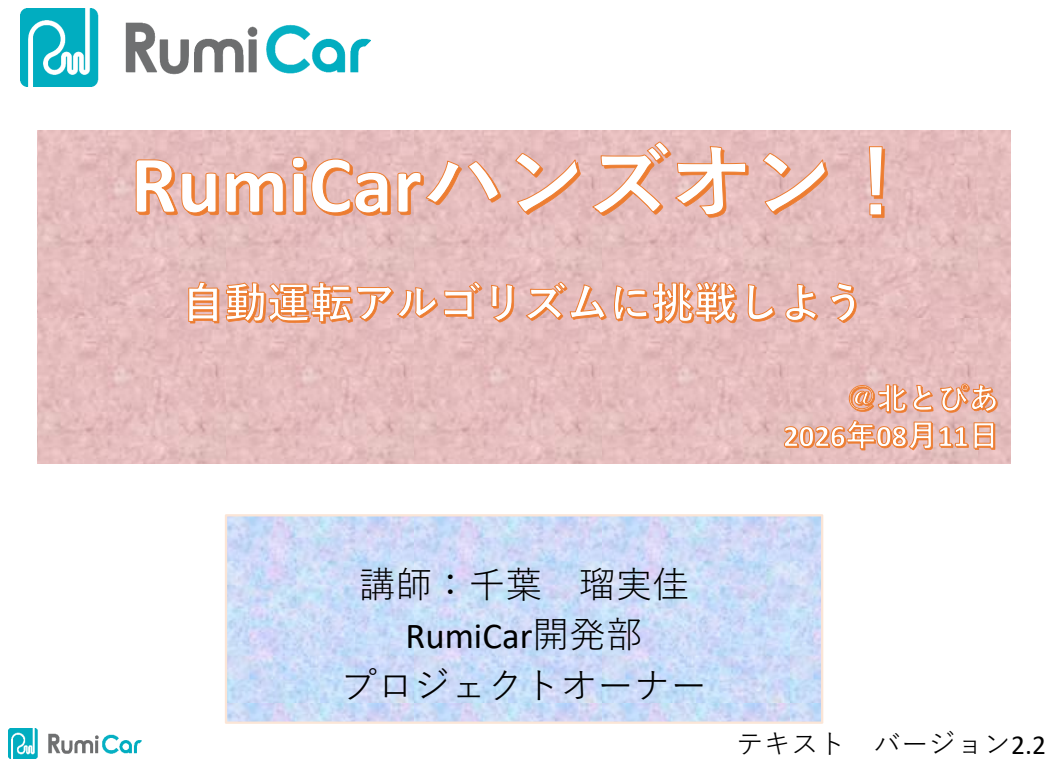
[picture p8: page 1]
テキスト バージョン2.2

講師：千葉 瑠実佳
RumiCar開発部
プロジェクトオーナー

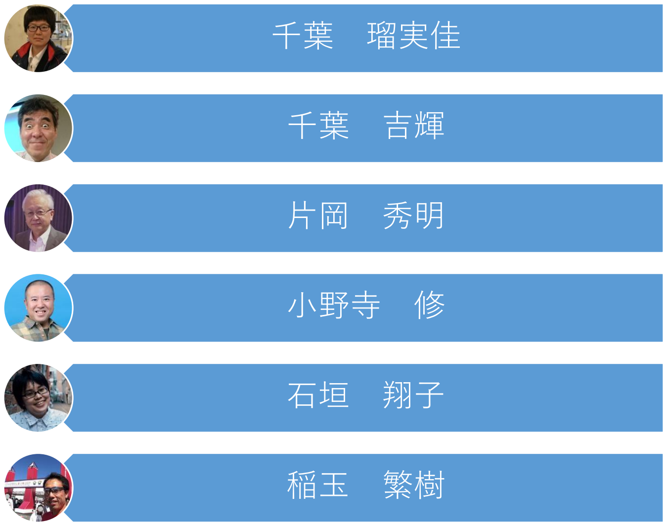
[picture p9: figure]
千葉 瑠実佳; 小野寺 修

製作・著作：RumiCar開発部 | 2

# 開発部 紹介

- 学べる内容 | 目次

## - RumiCarとは

- 準備

## - 距離の測定

- Exercise-1.1 中央のセンサで測距しよう！
- Exercise-1.2 ３つのセンサで測距だ
- Exercise-1.3 シリアルプロッタを使ってみよう

## - モータ制御

- Exercise-2.1 ハンドルを切る
- Exercise-2.2 速度制御
- Exercise-2.3 前進と後進
- Exercise-2.4 ジグザグ走行

## - 自律走行基礎

- Exercise-3.1 | 安全に停止する車
- Exercise-3.2 | 市街地を走る車

青字のところで
実際にプログラ
ミングするよ

# 学べる内容

## - RumiCarの仕組み

## - センサー - モータドライバ

## - レーザー測距モジュールを使った距離測定 - モータドライバ制御 - 自律走行基礎

## - その他として、良いプログラム開発のための関 数化の意義、なども学べます

# RumiCarとは

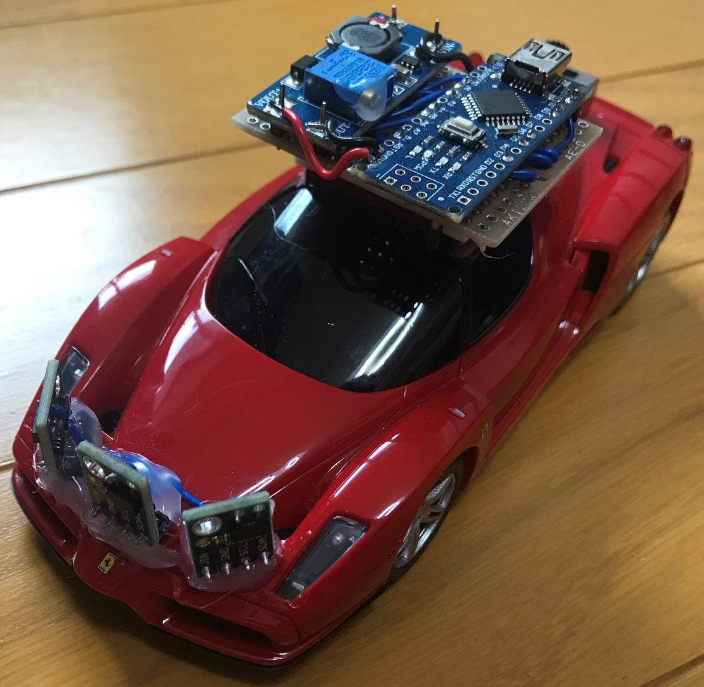
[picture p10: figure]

# RumiCarとは

## - 複数の車体と多様な種類のコンピュータモ ジュールを組み合わせて自律走行プログラムを 開発可能なプラットフォームです - レーザー測距モジュールを搭載していて障害物 迄の距離を計測することができます - モータの回転を制御することにより車速制御で きます

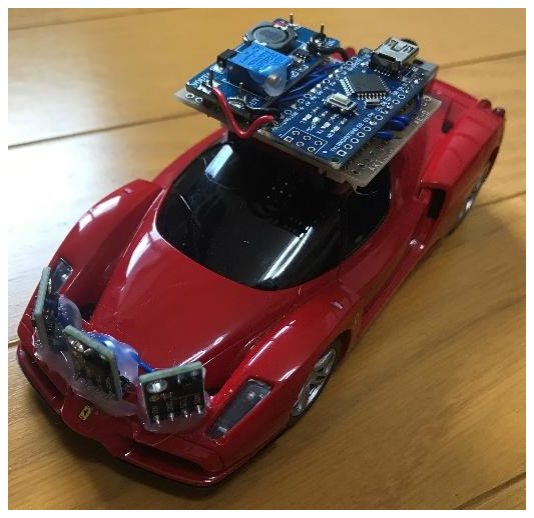
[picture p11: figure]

# コンピューターモジュール

(CM)

表面 | 裏面

# コンピューターモジュール (CM)基板化

## 開発・設計してくださったのは

大栄 | 豊 | 氏

コンピューターモジュール基板

センサー基板

SeeedのFusion PCBに発注。
納品された。

# 組み合わせ自由自在

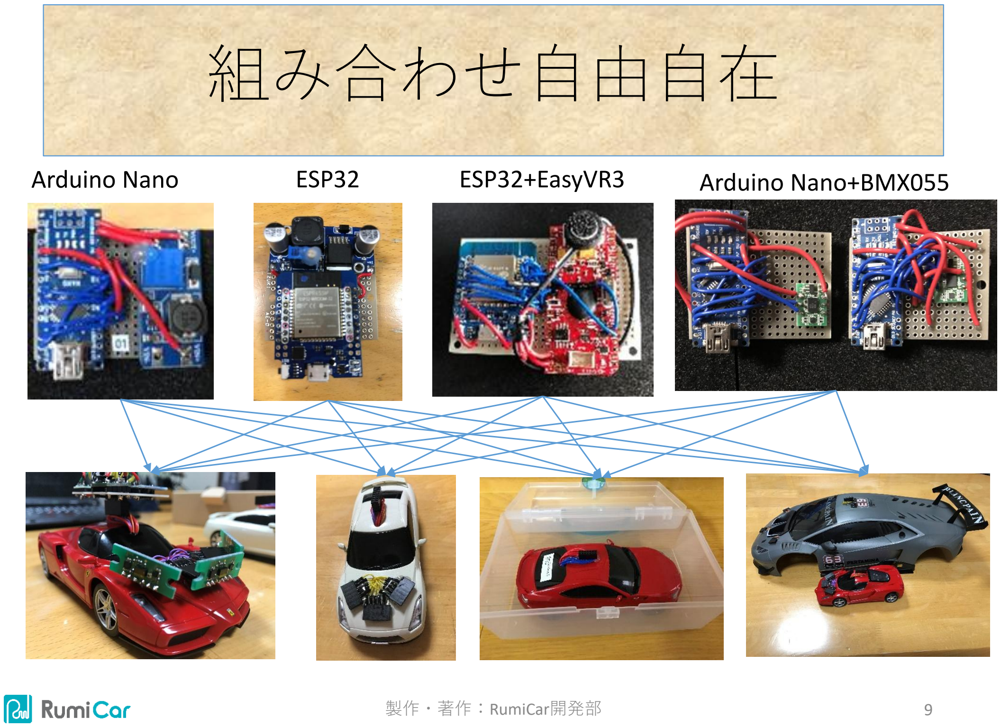
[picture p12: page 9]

Arduino Nano | ESP32 | ESP32+EasyVR3 | Arduino Nano+BMX055

# 組み合わせ自由自在

Pythonでコードを書き、
モーター制御などしてくださる
石垣 翔子 氏

次なる取り組み(挑戦)
Raspberry Pi
- コンピューターモジュール化
- モーター制御
- 画像認識

# ラズパイ版CM（カメラ付き）

# ラズパイ版CM（カメラ付き）

ラズパイ版CMをRumiCarに装着 | ラズパイ版CMのカメラで撮影

カメラ

# Obniz版CM

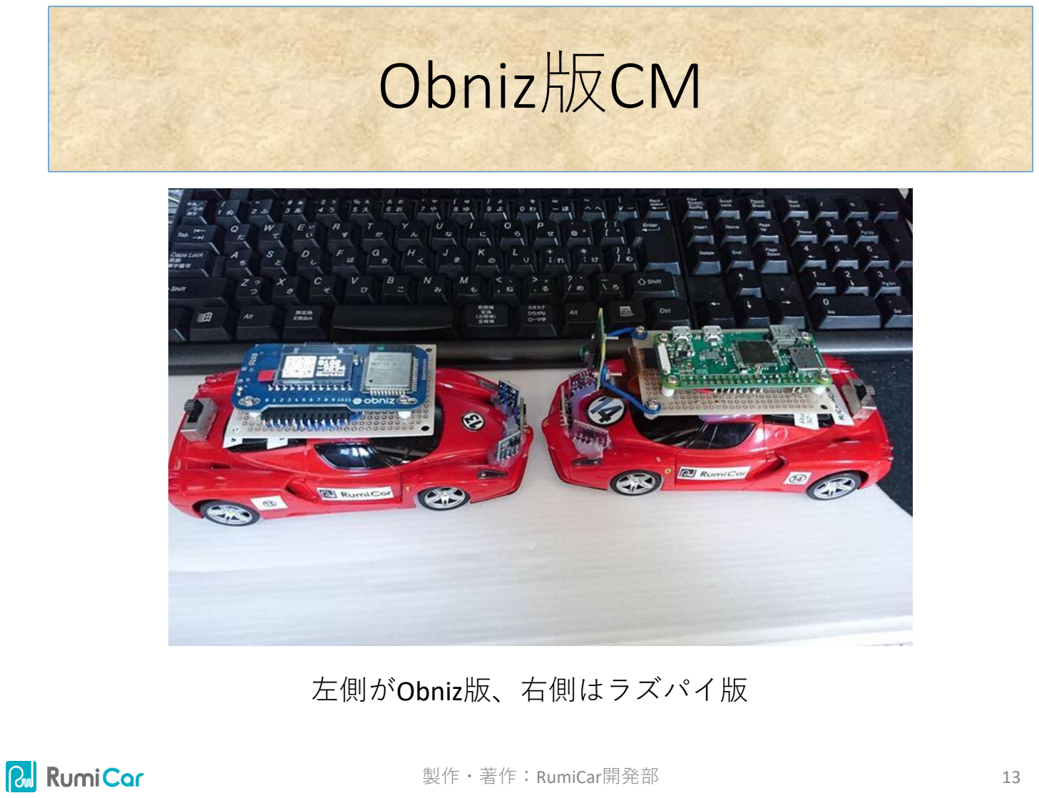
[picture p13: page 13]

左側がObniz版、右側はラズパイ版

カメラ

# ESP32版 Bluetooth接続（動画）

Bluetoothシリアル接続

BLE(Bluetooth Low Energy)マルチコネクト

https://youtu.be/-r6Vrhn5ifQ | https://youtu.be/UpEcTDvwYFw

# コンピュータモジュール比較

ボード | Arduino Nano | ESP32 | Raspberry Pi Zero W | Obniz | Spresense
電源 | 7-12V(VIN) (5Vラインへの供給 は非推奨) | 2.2-3.6V(3V3へ入力の場合) 3.7-6.0V(VINへ入力の場合) | 5V | 5V | 3.6-4.4V
内部動作電圧 | 5V | 3.3V | 3.3V | 3.3V
I/Oピン電圧 | 5V | 3.3V | 3.3V | 5V(電圧選択 可能) | 5V、3.3V切替
I2C電圧 | | | | | 1.8V
外部電源供給能力 | ピン当たり40mA 全体で100mA | 最大12mA | ピン当たり16mA 全体で50mA | 5Vモードで 1A | 6mA
消費電力(電流) | 65mA | WiFi時160-260mA | 125mA WiFi時270mA | 平均170mA (WiFi不使用 時)
PWMピン数 | 6本 | 4本 | ハード2本 | 6本
電源関係構成 | 電源:MT3608 VL/DRV:５Vラインよ り | PQ3RD23 (またはLM2596) | 電源:MT3608 (またはTPS63020) VL/DRV:PQ3RD23 (またはSOT-23AP7333) | MT3608 (または TPS63020)

# プログラミングで楽しめるよ

# 世界の友達と交流しよう！

プログラムのダウンロードや交換が
できるよ

## - 自分のプログラムをサーバー にアップしよう - おもしろそうなプログラムを 見つけたら自分のRumiCarにダ ウンロードして走らせてみよ

う

## - 世界の友達と交流しよう

予定・計画中です

# みんなで学ぼう！

教室を開催するよ

## - RumiCarを作ろう！ - コンピュータモジュー ルを作ろう！ - プログラムを作ろう！

予定・計画中です

# 歴代RumiCar(1号車～5号車)

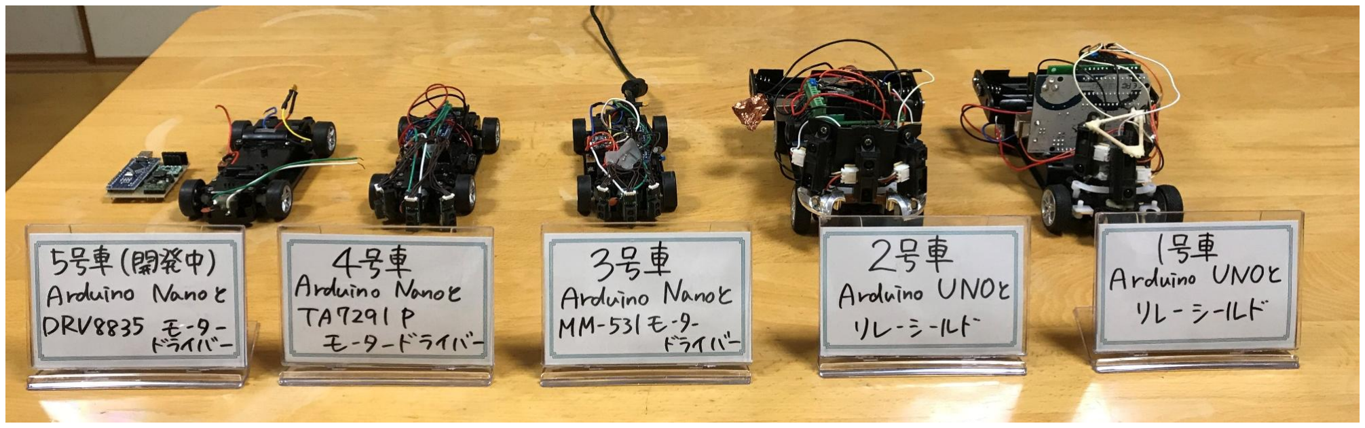
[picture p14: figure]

2017年8月3日撮影

# RumiCarの歴史(博物館)

1号車

２号車

4号車

3号車

# RumiCarの歴史(1号車と2号車)

２号車（遠隔操作型） | 1号車（自走型）

# RumiCarの歴史(1号車と2号車)

２号車（遠隔操作型） | 1号車（自走型）

# 2号車の説明

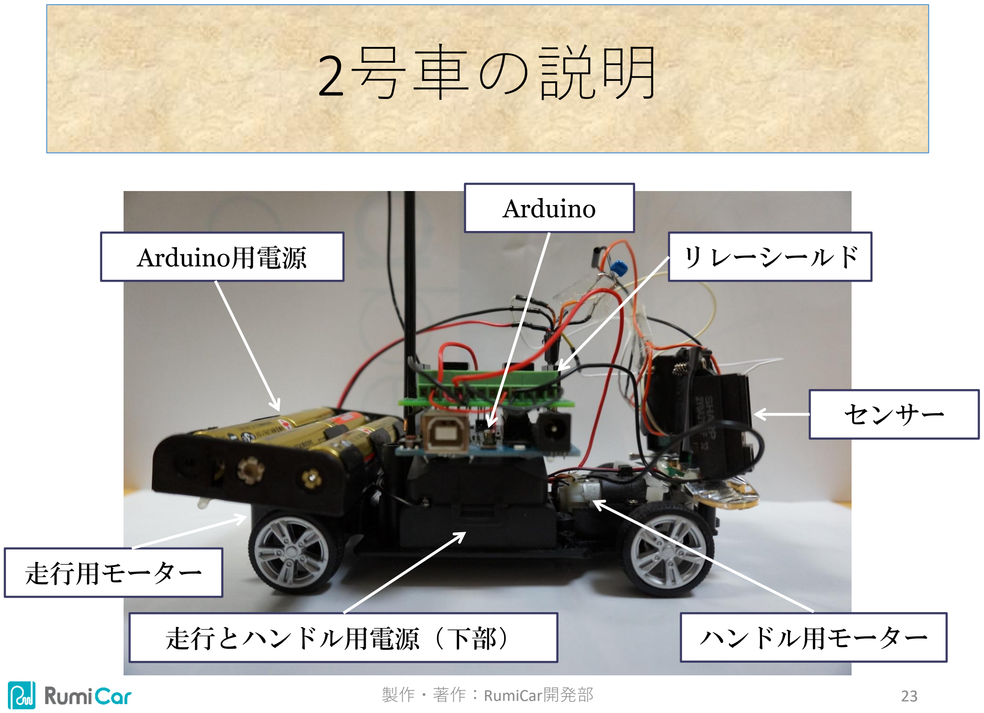
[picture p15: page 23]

走行とハンドル用電源（下部）

Arduino用電源

Arduino

センサー

ハンドル用モーター

走行用モーター

リレーシールド

# センサー動作試験（動画）

https://youtu.be/vIAL7uUnXTA

# ３、４号車センサー部分

# モータドライバ

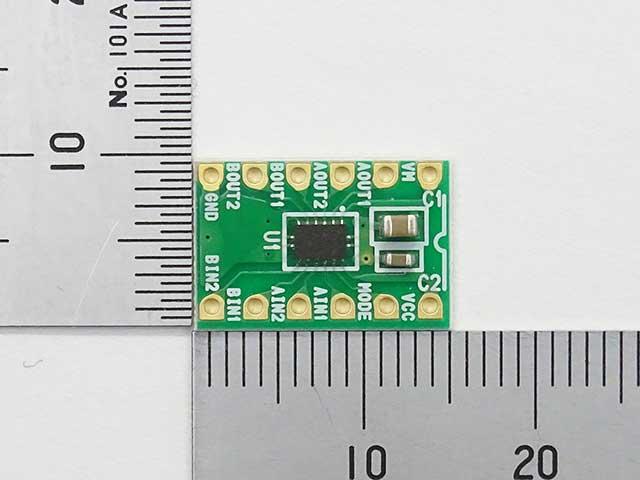
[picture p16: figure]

DRV8835 (http://akizukidenshi.com/catalog/g/gK-09848/) | DRV8835 秋月電子通商より

# モータドライバ

## - RumiCarに搭載されているモータドライバは DRV8835です

## - DRV8835の特徴

## - ２チャンネル - 各チャンネル1.5Aまで流せる - PWM(250kHz) - 低消費電力 - 低電圧降下（モータ側） - ロジック電源（VCC）とモータ電源が独立している

- ロジック電源電圧は2から7V
- モータ電源電圧は11Vまで

# DRV8835 (http://akizukidenshi.com/catalog/g/gK-09848/)

DRV8835 秋月電子通商より

# 開発中動画（動画）

https://youtu.be/8jULg3fZ-jw

# 開発中写真

# 開発中写真

# 開発中写真

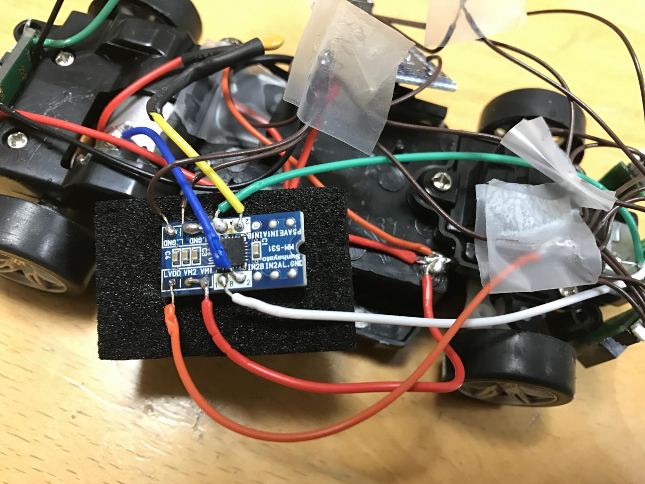
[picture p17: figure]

# 動作試験（動画）

https://youtu.be/8jULg3fZ-jw (https://www.youtube.com/watch?v=7sBWRta5f8w&list=PLizQwd7qivbjCSXyGGtFbZfkKpPRBjdZD&index=14)

# 動作試験（動画）

https://youtu.be/8jULg3fZ-jw

# ４号車システム部分

# 動作試験（動画）

https://youtu.be/dP815X6oKPw

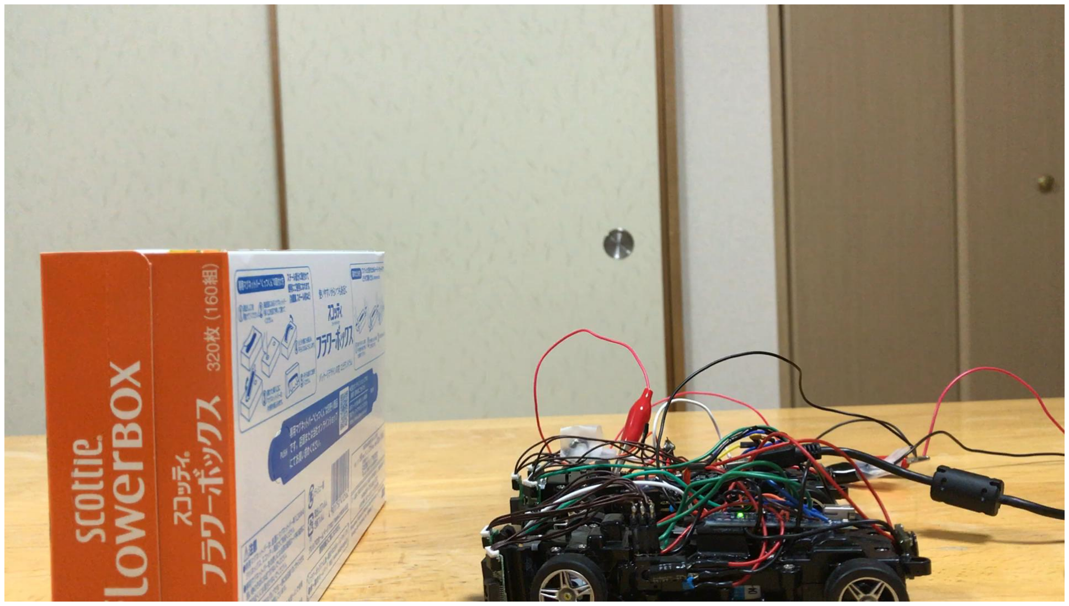
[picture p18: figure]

6号車

製作・著作：RumiCar開発部
36

6号車

37

7号車

製作・著作：RumiCar開発部
38

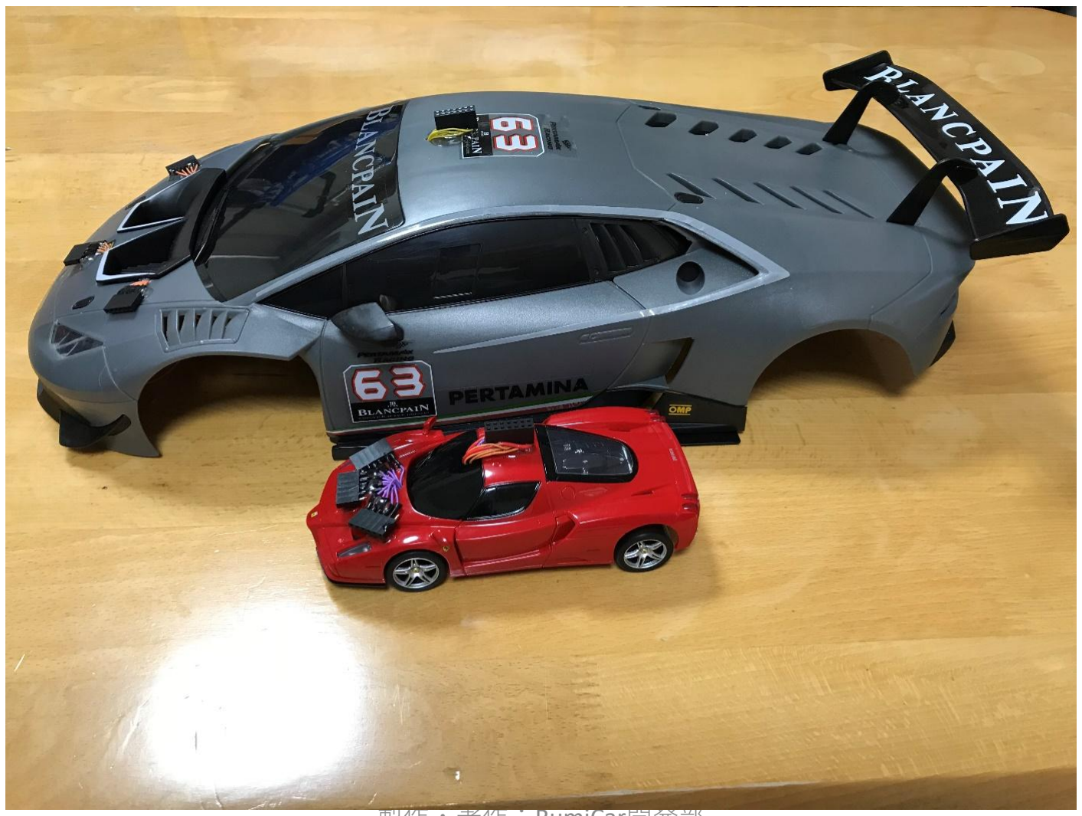
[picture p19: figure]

製作・著作：RumiCar開発部

# インターフェイスの標準化

39

# RumiCarの歴史と構成

モータドライバBD6212HFPは小さすぎて使用断念

号車 | 1号車 | ２号車 | ３号車 | ４号車 | ５号車
ベース車スケー ル | 1/24 | | 1/32
コントローラー | Arduino UNO | | Arduino Nano | | モジュール式 （選択交換可能）
モータ制御 | リレーシールド | | MM-531 | TA7291P | DRV8835
測距モジュール | GP2Y0A21YK | | GP2Y0E02A | | VL53L0X
測距方式 | 赤外線 | | | | レーザー
Arduino電源 | 単三乾電池６本 （９V） | | 単四乾電池(4.5V)よりLMR62421を使い ７Vに昇圧
測距モジュール 電源 | Arduinoより供給 | | TA48033Sで3.3Vを生成

# 第3世代配線図

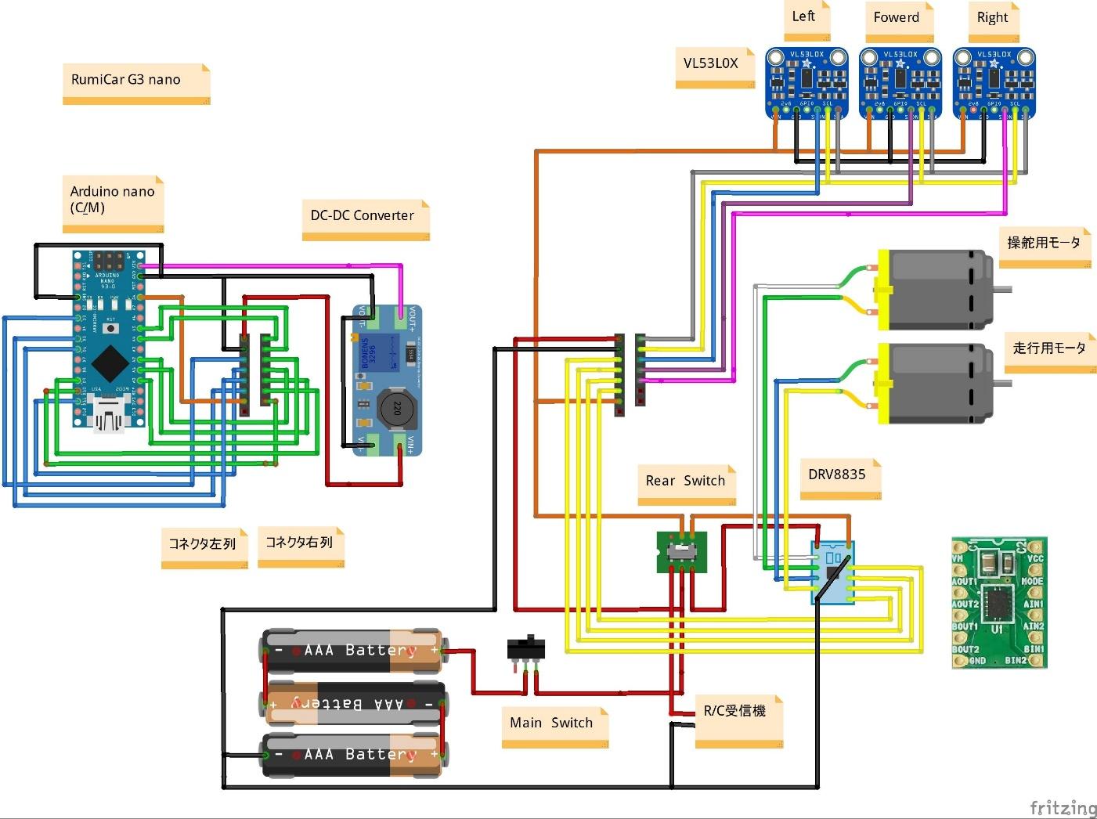
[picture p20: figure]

# インターフェイス

旧型式 | NEW

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
誤挿入防止用ダミーピン

# 8×7ピン インターフェイス

誤挿入防止用7.5をダミーピンとして追加

準備

## 注意点、必要なもの、準備

# ケーブルの抜き差し注意点

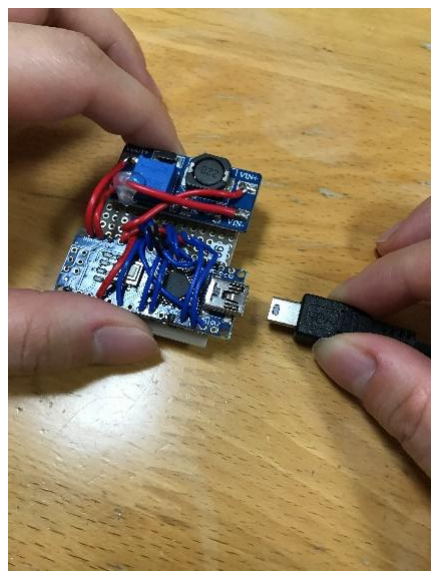
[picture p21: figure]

# コンピュータ制御へ設定

- （一部のモデルのみ）
- マニュアル制御とコンピュータ制御の切
り替えスイッチ好きモデルは切り替えス
イッチを右側へ切り替えます
- 右側がコンピュータ制御側です
- 右側にするとCM（ArduinoやESP32）から の命令で走ります
- （左側にするとラジコンで操作できるよ
うになります）

# ケーブルの抜き差し注意点

## - まず、コンピュータモジュールにUSBケーブル を接続する - それから、コンピュータモジュール(以下CMと 呼びます)を車体に接続する - 注意！車体にCMを装着した状態でコンピュー タモジュールにUSBケーブルを接続しないこと - 車体にCMを装着したままUSBケーブルを抜か ないこと - CMコネクタ部分に過度な力が加わり破損の原 因になります

# Arduino IDEのインストール

## - URL:https://www.arduino.cc/en/Main/Software

- 「Windows Win 10 or newer(64-bit)」をインストール
- (既にインストール済の人はこの作業は飛ばしていただいて結構です)

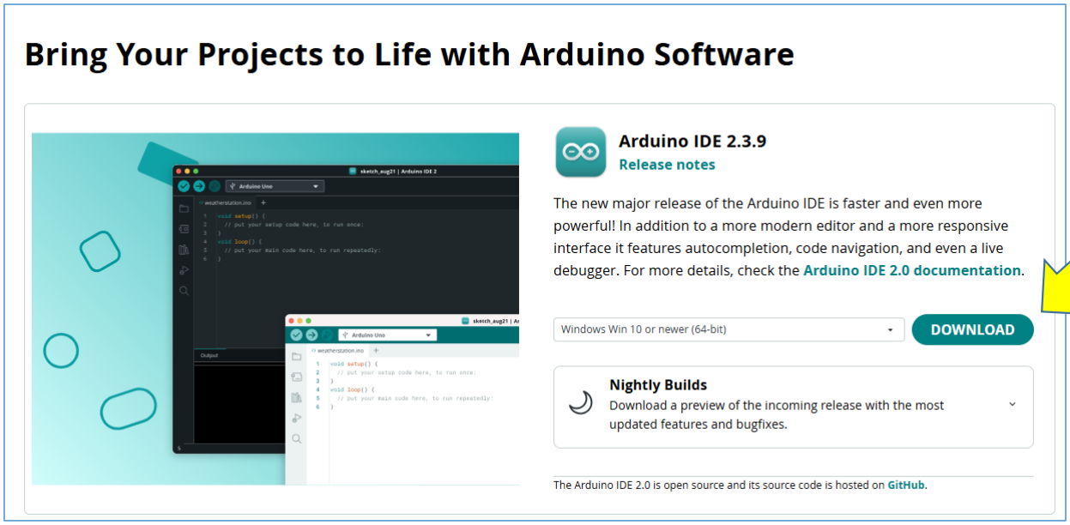
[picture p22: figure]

# RumiCarライブラリのインストール

## - Arduino IDEを開く

- 「ツール」- >「 ライブラリを管理…」で「 RumiCar」を検索しインストール を押下する。依存関係も含めて「全てをインストール」する

# COMポートの確認 （Windowsの場合）

- RumiCarのコンピュータモジュールをUSBケーブルでパソコンに接続す る
- デバイスマネージャで接続されたCOMポート番号を確認する。CH340 を探します（COM番号を覚えておくこと）

確認(この例では4番)

# Arduino IDEの設定

## - ボード：Arduino Nano - プロセサ：ATmega328P(Old Bootloader) - シリアルポート：デバイスマネージャで確認した番号

# COMポートの確認 （Macの場合）

- Terminalソフトを起動します
- コマンド”ls –l /dev/tty.usb*”と入力することで接続されているCOMポー トの一覧を表示させます
- Arduinoが接続されたCOMポートを確認する
- 下記の例では「usbserial-14120」（覚えておくこと）

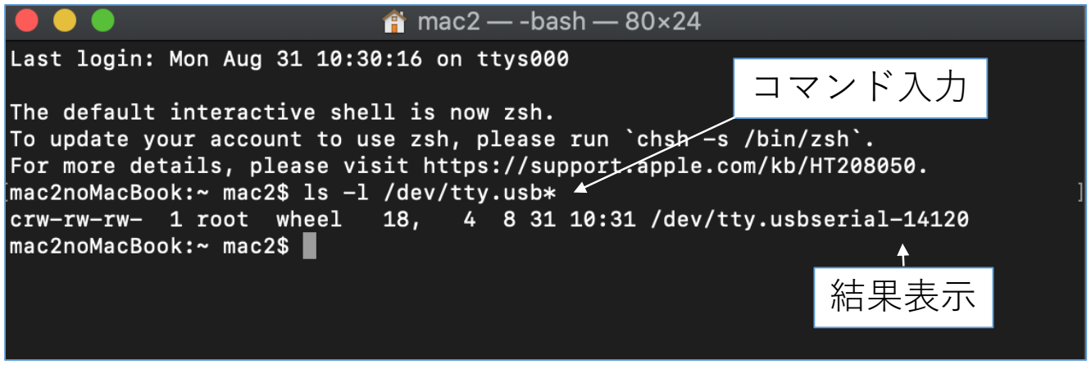
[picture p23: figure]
コマンド入力; 結果表示

# Arduino IDEの設定 (Macの場合)

## - ボード：Arduino Nano - プロセサ：ATmega328P(Old Bootloader) - シリアルポート：Terminalで確認したデバイス

# 設定の確認

## - 重要！ もう一度、確認しよう！

項目 | 設定 | 備考
ボード | Arduino Nano | Arduino UNOでは動きません
プロセッサ | ATmega328P(Old Bootloader) | Old Bootloaderのほう
シリアルポート | “デバイスマネージャで確認し た番号” | ボードを変えると、変わった りしますので注意
書込装置 | USBasp | ユーザ自身でデフォルトから 変えている場合があります
シリアルポートの ボーレート | 9600bps | Arduino Nanoでは9600bpsに設 定されている必要があります Arduino IDEのシリアルモニタ を開いて確認します

# 距離の測定

## レーザー測距モジュール

# 測距モジュール

## - 測距モジュールの比較

型番 | GP2Y0A21YK0F | GP2Y0E02A | VL53L0X | HC-SR04
測定方法 | 赤外線 | 赤外線 | レーザー | 超音波
出力 | アナログ | アナログ | ディジタル値 | アナログ
推奨電源電圧 | 5V | 3.3V | 2.6-5.5V (ボード依存) | 5V
消費電力 | 最大40mA | 最大36mA | 20mA | 15mA
測定可能距離 | 80cm | 50cm | 2m | 2m
RumiCarでの採用 | 1、2号車 | 3、4号車 | 5号車以降 | 非採用
備考 | 出力と距離が比例 しない | | | 高速移動時のエ コーキャンセル処 理問題

グラフはシャープ社データシートより

# レーザー測距モジュール

## - 車体前方に３基搭載

左 ：０
中央：１
右 ：２

センサ０

センサ１
センサ２

センサ０

センサ１

センサ２

# VL53L0X

## - Rumicarに搭載されているレーザー測距モ ジュールはVL53L0Xです - VL53L0Xの特徴

## - 最大２ｍまで計測可能 - I2Cで測定値を取得可能 - I2Cアドレスはソフトウエアにより再設定可能 - パラメータ設定により大まかにモード設定可能

- 高速測定モード
- 長距離測定モード
- 高精度測定モード
- サンプルプログラムは高速測定モードに設定されてます

# 測距方法

## - 各測距モジュールの測距値の取得は、例えば下 記の命令を使います。結果は整数値（int）で ｍｍ（ミリメートル）の単位で得ることができ

ます

## readRangeSingleMillimeters()

## - センサ1の測定値を取得するには例えば下記の ようにします

i = sensor1.readRangeSingleMillimeters();

# GitHubからExerciseをダウンロード

https://github.com/RumiCar-group/RumiCar

Exerciseのヘッダー作製、

リファクタリング、上級編プログラムの追加を
してくださったのは
稲玉 繁樹 氏

【注意】Exercise-A2.3と3.1は、
このイベントでは使用しません。

# Exercise-1

## 距離を測ってみよう

# Exercise-1.1

## 中央のセンサで測距しよう！

# Exercise-1.1

# 中央のセンサで距離を測る(準備)

## - RumiCarの車体の電源をオフにします - CMをRumiCarの車体より取り外してください - CMにUSBケーブルを接続します - USBケーブルをパソコンに接続します - CMをRumiCarの車体に取り付けます

# Exercise-1.1

# 中央のセンサで距離を測る

## - Arduino IDEでファイル”Exercise”を開きます - プログラムの下の方のところに計測値を表示す るコードを追加します

- Serial.print命令やSerial.println命令 でシリアルモニタにデータを表示
できるよ
- Serial.printは改行無し
- Serial.printlnは表示後改行ありだよ

# Exercise-1.1

# 中央のセンサで距離を測る

## - コンパイルとボードへの書き込み

押す

# Exercise-1.1

# 中央のセンサで距離を測る（続き）

## - シリアルモニタで測定値を表示させます

## - ツール -> シリアルモニタ

# Exercise-1.1

# 中央のセンサで距離を測る（続き）

- うまく表示できない場合はボーレートを確認してみてください。 （9600 bpsになっている必要があります）

# Exercise-1.1

# 中央のセンサで距離を測る（続き）

- うまく表示できない場合は「準備」の項の「設定の確認」のペー ジの内容を再度確認してください

# Exercise-1.2

## ３つのセンサで測距だ！

# Exercise-1.2

# ３つのセンサで距離を測る

## - ファイル”Exercise-1.2”を開きます

センサー センサーの場所

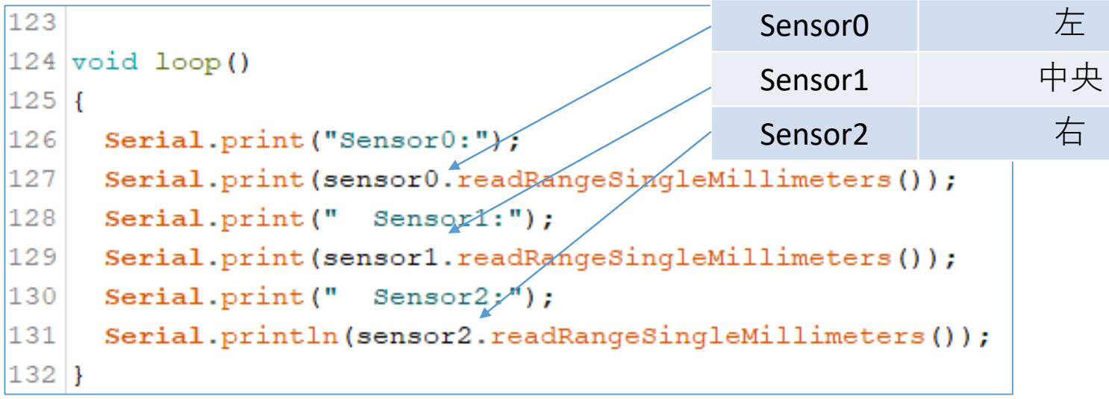
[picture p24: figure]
Sensor0; Sensor1; Sensor2

# Exercise-1.2

# ３つのセンサで距離を測る（続き）

## - シリアルモニタで測定値を表示させる

## - ツール -> シリアルモニタ

# Exercise-1.3

## シリアルプロッタを使ってみよう

# Exercise-1.3

# シリアルプロッタを使ってみよう

## - （プログラムはそのままExercise-1.2のものを使います） - シリルモニタを閉じる - ツール -> シリアルプロッタ

- ※シリアルモニタのウインドウが開いている場合は閉じる必要が あります

| 紫外線硬化樹脂 | ホットメルト接着剤 （通称グルー）
長所 | • 短時間で固まる • 強度も高い • 透明で見栄えが良い • 重ね塗りが可能 | • 安い • 失敗しても剥がしてやり直しが効く

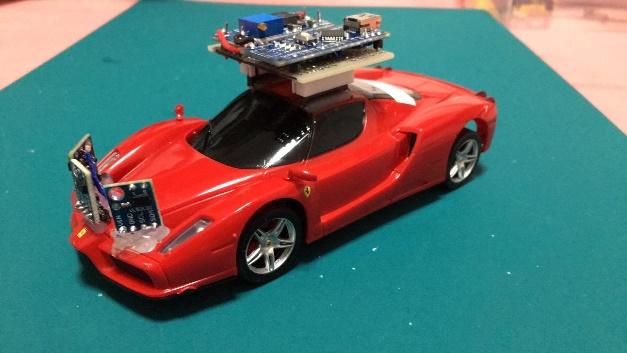
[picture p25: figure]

短所 | • 長期間経過すると脆く なり崩れる | • 透明でないので見栄えが良くない （イ〇スタ映えしない） • 紫外線硬化樹脂程強度がない

# モータ制御

## ハンドルを動かす、走る

# モータドライバ

## - RumiCarに搭載されているモータドライバは DRV8835です - DRV8835の特徴

## - ２チャンネル - 各チャンネル1.5Aまで流せる - PWM(250kHz) - 低消費電力 - 低電圧降下（モータ側）

## - ロジック電源（VCC）とモータ電源が独立している

- ロジック電源電圧は2から7V
- モータ電源電圧は11Vまで

DRV8835 (http://akizukidenshi.com/catalog/g/gK-09848/)

# DRV8835諸元(1/2)

DRV8835 Dual Low-Voltage H-Bridge ICデータシート 2016年8月9日 より

# DRV8835諸元(2/2)

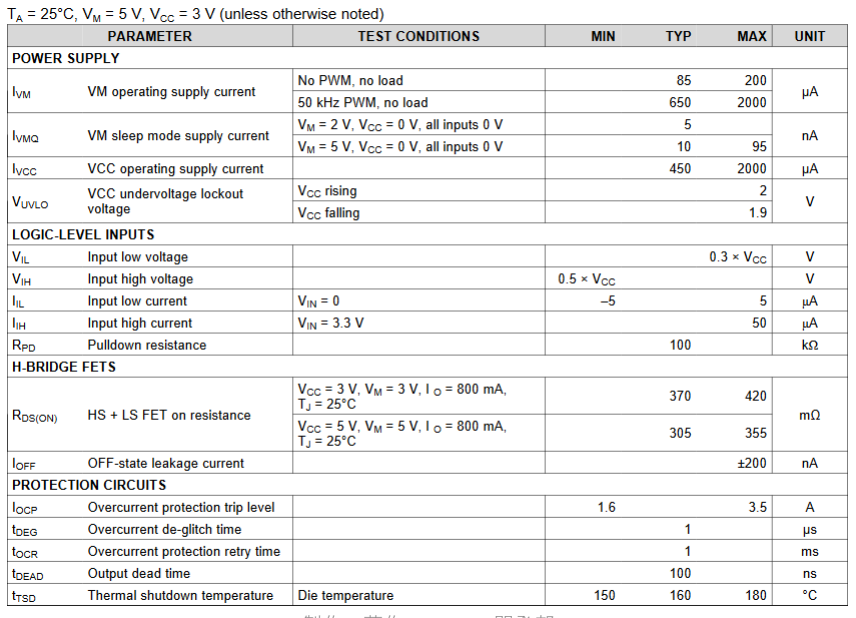
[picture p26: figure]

製作・著作：RumiCar開発部 | 78 DRV8835 Dual Low-Voltage H-Bridge ICデータシート 2016年8月9日 より

# IN/INモード

DRV8835 Dual Low-Voltage H-Bridge ICデータシート 2016年8月9日 より

## - IN/INモードとPHASE/ENABLEモードを持ってい

ます

## - RumiCarではDRV8835をIN/INモードで利用しま

す

# Phase/Enableモードの場合

DRV8835 Dual Low-Voltage H-Bridge ICデータシート 2016年8月9日 より

## - Enableが1の時、モーターが回転 - Enableが0の時、モーターが停止 - Phaseが1の時は逆回転の向き - Phaseが0の時は正転の向き

Enableが回転数、Phaseが回転方向

# PWMの説明

## - RumiCarでは走行速度制御にPWM技術を利用し ています - PWMとは”Pulse Width Modulation”の略語で電圧 を短い間隔でオンとオフを繰り返すことによっ て見かけの電圧を変化させる技術です

製作・著作：RumiCar開発部; 図はWiKipedia 81 より

# ArduinoのPWM

## - ArduinoのPWMはタイマと連動しています - Arduinoのタイマは3個あります

## - ArduinoのServoライブラリを使うとタイマ1は 使えなくなってしまいます

タイマ | ピン | 周波数
タイマ0 | 5、6 | 980Hz
タイマ1 | 9、10 | 490Hz
タイマ2 | 3、11 | 490Hz

Arudino版でのピンアサイン
機能 | タイマ | ピン
操舵 | タイマ2 | 3、11
走行 | タイマ0 | 5、6

# RumiCarでのPWM制御

## - RumiCarのプログラムサンプルではピンにマクロ設 定をしています - 例えば右にハンドルを曲げたいときはAIN1をオン、 AIN2を”0”に設定します - ※この例はArduino版のピンアサインです。ESP版 などはピンアサインが異なりますがマクロを使っ てピンアサインの違いを意識することなくプログ ラムを開発できるようにしてあります

タイマ | 機能 | ピン | マクロ設定
タイマ2 | 右折 | 3 | AIN1
| 左折 | 11 | AIN2
タイマ0 | 前進 | 5 | BIN1
| 後進 | 6 | BIN2

# RumiCarでのRC関数

## - RumiCarではプログラムを開発しやすいように 下記関数を用意しました

動作 | 関数の型 | 関数名 | 第一引数 (int) | 第二引数 (int) | 動作 | エラー時の戻り値
操舵 | int | RC_steer | RIGHT | (無し) | 右操舵 | 0
| | | LEFT | | 左操舵
| | | CENTER | | 中央
走行 | int | RC_drive | FREE | 0から255 (PWM値) | ニュートラル | 0
| | | REVERSE | | 後進
| | | FORWARD | | 前進
| | | BRAKE | | ブレーキ
- RC_driveのFREE時の第二引数の値は指定は必要ですが値自体は無視されます
- RC_driveの第二引数の値はPWM値であり値が大きいほどモータに電力を掛けることができます
- 第一引数はint型です。この表の値を指定すると最終的にマクロで展開されます

# 関数を用意することの意義

## - RumiCarではマクロ設定や独自関数としてRC関 数を追加するなどにより下記のメリットを提供 します

## - 複数の命令をまとめているのでプログラムがすっき りし可読性が向上する - 固定の引数の記載を省くことによりプログラムが すっきりし可読性が向上する - 不要な記載を省くことによるプログラムミス低減 - ハードウエアの差異によるピンアサインや制御方法 等の考慮の不要化 - コンピュータモジュール間の差異を吸収しプログラ ムの共通化

# 共通化ストラクチャ

# RC_steer関数の利用例

## - RC_steer関数を利用した操舵プログラミングの 例です - 左側にオリジナル命令での記述を示します


オリジナル命令での記述 | RC関数利用の記述

# Exercise-2

## モータ制御

# Exercise-2.1

## ハンドルを切る

# Exercise-2.1

# ハンドルを切る(準備)

## - RumiCarの車体の電源をオフにします - CMをRumiCarの車体より取り外してください - CMにUSBケーブルを接続します - USBケーブルをパソコンに接続します - ファイル”Exercise-2.1”を開きます

# Exercise-2.1

# ハンドルを切る（プログラム）

- delay命令はそのまま何もしないで
指定時間だけ待つよ
- delayの引数の単位はミリ秒だよ
- このプログラムはハンドルを切っ
たまま0.5秒(500ミリ秒)そのまま
ハンドルを保持するよ
- ハンドルを右に切る
- 0.5秒そのまま
- ハンドルを左に切る
- 0.5秒そのまま

繰り返す

# Exercise-2.1

# ハンドルを切る(試験)

## - コンパイルしてプログラムをCMに書き込みま

す

## - CMからUSBケーブルを取り外します - CMをRumiCarの車体に取り付けます - RumiCar車体の電源をオンにしてください - ハンドルが左右に曲がっていますか？

# Exercise-2.2

## 速度制御

# Exercise-2.2

# 速度制御(準備)

## - RumiCarの車体の電源をオフにします - CMをRumiCarの車体より取り外してください - CMにUSBケーブルを接続します - USBケーブルをパソコンに接続します - ファイル”Exercise-2.2”を開きます

# Exercise-2.2

# 速度制御(プログラム)

- RC_driveの第二引数、255とか200
とか150はPWMの値です
- 255が最大で128が最大値の約半分
の値になります
- 値を下げてゆくとタイヤの回転も
だんだんと遅くなります

# Exercise-2.2

# 速度制御(実走試験)

## - CMからUSBケーブルを取り外します - CMをRumiCarの車体に取り付けます - まず、いきなり走らせないでRumiCarの車体を 手で持ち上げたままにします - RumiCar車体の電源をオンにしてください - タイヤの回転が変化していますか？

## - RumiCarをそっと机に置いてみましょう

# Deep knowledge

## 直流モータの低回転制御 稲玉 繁樹 氏

# RumiCarのモータ制御


Deep knowledge
- RumiCarは２つのモータを制御しています。
- ステアリング
- 走行

オンオフ制御
全力でモータをオンしている

PWM制御
電圧を変えている

・角度が決められない
・電流が流れすぎている

車両条件などで速度安定しない
速度と電圧が比例しない

# RumiCarのモータ制御

## - 低速で動かしたいが，走行指令 120/255 以下は動かない

- 原因１：PWM周期が高すぎる
- 原因２：DCモータは始動時に大きい電流が必要
Z=jωL ・・・ (1) ω=2πf ・・・ (2)
≒ 見かけの抵抗が高くなりPWM指令が低いと電流が小さく始動できない よって，使えるPWM範囲が狭くなっている。
- 対策１：PWM周期を変更
- 976kHz → 244Hz
- 対策２：始動ブーストを導入
- 始動時の数10ms はPWM大きく

PWMとは

Time

PWM

# Advanced ソフトの解説

Deep knowledge

- A2-3低速で走らせるため
- B2-3低速動作をライブラリへ
- B2-5縦列駐車にチャレンジ
動画で確認！

PWM周期を下げる
→ 低い値でも電流が流れる
始動時強く，動き出したら弱く
→ 40位まで動くようになりました

PWMドライバを定時割込化
始動時ブーストを自動化
→ 意識せずに低速動作が可能

注：PWM周期変更によりDelay()の周期
がずれるため，RC_delay()を使うこと

# Exercise-2.3

## 前進と後進

# Exercise-2.3

# 前進と後進(準備)

## - RumiCarの車体の電源をオフにします - CMをRumiCarの車体より取り外してください - CMにUSBケーブルを接続します - USBケーブルをパソコンに接続します - ファイル”Exercise-2.3”を開きます

# Exercise-2.3

# 前進と後進(プログラム)

- RC_driveの第一引数がFORWARD
を指定した時に前進
- 第一引数がREVERSEの時に後進
- 前進する
- 0.5秒そのまま（前進し続ける）
- 後進する
- 0.5秒そのまま（後進し続ける）

繰り返す

# Exercise-2.3

# 前進と後進(実走試験)

## - コンパイルしプログラムをCMへ書きこみます - CMからUSBケーブルを取り外します - CMをRumiCarの車体に取り付けます - まず、いきなり走らせないでRumiCarの車体を 手で持ち上げたままにします - RumiCar車体の電源をオンにしてください - タイヤが前進と後進を繰り返してますか？

## - RumiCarをそっと机に置いてみましょう

# Exercise-2.3

# 前進と後進(発展問題)

## - （発展問題）なるべくスリップしないようにし て前進と後進を繰り返すようにするにはどうし たら良いでしょうか？

# Exercise-2.4

## ジグザグ走行

# Exercise-2.4

# ジグザグ走行（準備）

## - RumiCarの車体の電源をオフにします - CMをRumiCarの車体より取り外してください - CMにUSBケーブルを接続します - USBケーブルをパソコンに接続します - ファイル”Exercise-2.4”を開きます

# Exercise-2.4

# ジグザグ走行(プログラム)


- 前進する
- ハンドルを右に切る
- 0.5秒そのまま（右に進み続ける）
- ハンドルを左にきる
- 0.5秒そのまま（左に進み続ける）

繰り返す

# Exercise-2.4

# ジグザグ走行(実走試験)

## - コンパイルしプログラムをCMへ書きこみます - CMからUSBケーブルを取り外します - CMをRumiCarの車体に取り付けます - まず、いきなり走らせないでRumiCarの車体を 手で持ち上げたままにします - RumiCar車体の電源をオンにしてください - RumiCarは予想通りの動きをしていますか？

## - RumiCarをそっと机に置いてみましょう

# 自律走行基礎

## センサによる車体制御

# 自律走行基礎

## - 自律走行はセンサ等で得られた情報や、既に自 分が持っている情報など、またそれらを組み合 わせて自動車を自動で最適に運転させることで

す

## - この章では自律走行の基礎として簡単な例を考 えてみます

# 自律走行基礎(状況の仮定)

## - 次のような単純な自律走行の状況を仮定します

## - 前進走行中に前方に障害物を検知したら障害物に衝 突しないように安全に停車する

## - 障害物を検知して停車中に障害物がなくなったら再 度前進を再開する

# Exercise-3

## 自律走行プログラムを開発しよう！

# Exercise-3.1

## 安全に停止する車

# Exercise-3.1

# 安全に停止する車

## - 単純な条件として具体的に下記を仮定します

## - RumiCarの中央センサ(Sensor1)で障害物を検知しな がら、障害物が検知されない場合は前進します

## - 障害物の例えば10cm手前で停車、障害物がなく なったら再度前進再開します

# Exercise-3.1

# RumiCarでの開発にあたっての考慮事項

## - 距離の測定誤差

## - サンプルプログラムのVL53L0X設定である高速測定 モードでは高速に測定するため若干精度が犠牲にな ります。そのため測距時に1~2cmの誤差が発生しま す。余裕を見込んだ距離判定をしましょう

## - 測定不能時の処理

## - 測定結果で8190前後の値はレーザーの反射が得られ ない場合の値です。つまりは測定範囲内に障害物を 検知できなかった場合の値になります

# Exercise-3.1

## RumiCarでの開発にあたっての考慮事項(続き)

## - 地面等の検知

## - センサのレーザーは円錐形に照射されます。 RumiCarは小さいので車上のセンサ搭載位置が低く 円錐形に照射されたレーザーはいずれ距離測定限界 より先に地面や床等を捉えてしまいます。この距離 はRumiCarモデル32型でだいたい30cm前後です。こ れらより障害物としての検知距離は30cm以下とし てください

## - 急停止処理

## - 走行状態から停止や後進命令を出しても慣性（勢 い）が付いているため直ぐには停止できません。で きれば上手な減速や停止の方法を考慮しましょう

# Exercise-3.1

# プログラミング上の条件まとめ

項目 | 条件
使用センサ | 中央センサ(Sensor1)のみ使用する
挙動 | 設定距離内に障害物を検知したら停止する
設定距離 | 10cmとする。ただし誤差を考え実範囲は10±2cmとする
信頼距離 | 30cm以内とする
測定不能時の値 | 8190、但し誤差を含むことがあるので注意

# Exercise-3.1

# 開発時のちょっと一工夫

## - 判断条件を単純に障害物がない、とのロジック としてしまうと前方に障害物がない場合は RumiCarがどこまででも走っていってしまいま す。これだとうっかり机の上などにRumiCarを おいてしまうとRumiCarが机から飛び降りてし まいます。机の上で動作テストなどをする可能 性がある場合においては安全も考えて例えば 30cm以内に障害物がある場合のみ走るなどと 条件を追加するなど工夫すると良いでしょう。 開発時にRumiCarをうっかり破損させてしまう 危険性を低減できます

# Exercise-3.1

# 安全に停止する車（動画）

https://youtu.be/95pc_4Wf14U

# Exercise-3.1

# 安全に停止する車（動画）

https://youtu.be/95pc_4Wf14U

# Exercise-3.1

# 安全に停止する車(準備)

## - RumiCarの車体の電源をオフにします - CMをRumiCarの車体より取り外してください - CMにUSBケーブルを接続します - USBケーブルをパソコンに接続します - ファイル”Exerise-3.1”を開きます

# Exercise-3.1

# 安全に停止する車(プログラム)

- 障害物が30cm以内にあるか？
- （無い場合は何もしない）
- （ある場合は次を実行）
- 障害物が12cmを超える->前進
- 障害物が8cm未満->後進
- 8cm以上12cm以下->ブレーキ

繰り返す

# Exercise-3.1

# 安全に停止する車(実走試験)

## - コンパイルしプログラムをCMへ書きこみます - CMからUSBケーブルを取り外します - CMをRumiCarの車体に取り付けます - RumiCar車体の電源をオンにしてください - 手を中央センサーに近づけたり話したりしてみ ましょう。RumiCarは予想通りの動きをしてい ますか？

## - RumiCarをそっと机に置いてみましょう

# Exercise-3.2

## 市街地を走る車

# Exercise-3.2

# 市街地を走る車

## - 単純な条件として具体的に下記を仮定します

## - 市街地に見立てた、道路の両側に壁がある道路を走 ります

## - 両側の壁の距離を測って道路の中心を走ります

## - 先行車の例えば10cm手前で停車、先行車がなく なったら再度前進再開します

# Exercise-3.2

# 市街地を走行する車（動画）

https://youtu.be/jyq4Ph0mCDM


# Exercise-3.2

# 市街地を走行する車(準備)

## - RumiCarの車体の電源をオフにします - CMをRumiCarの車体より取り外してください - CMにUSBケーブルを接続します - USBケーブルをパソコンに接続します - ファイル”Exrcise-3.2”を開きます

# Exercise-3.2

# 市街地を走行する車(プログラム)

# Exercise-3.2

# 市街地を走行する車(実走試験)

## - コンパイルしプログラムをCMへ書きこみます - CMからUSBケーブルを取り外します - CMをRumiCarの車体に取り付けます - RumiCar車体の電源をオンにしてください

## - RumiCarをそっとコースに置いてみましょう
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

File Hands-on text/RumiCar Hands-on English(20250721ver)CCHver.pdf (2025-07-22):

# RumiCar Hands-On

Project Owner; Text Version 2.11

Workshopping Self-Driving Car Algorithms

Lecturer: Rumika CHIBA
RumiCar Development Team

製作・著作：RumiCar開発部

- Résumé | Index
- Introducing the RumiCar
- Preparation
- Ranging
- Exercise-1.1 Ranging With The Central Sensor
- Exercise-1.2 Ranging with 3 Sensors
- Exercise-1.3 Using the Serial Plotter
- Motor control
- Exercise-2.1 Steering
- Exercise-2.2 Speed Control
- Exercise-2.3 Forward and Reverse Movement
- Exercise-2.4 Zig-Zagging Movement
- Autonomous Driving Basics
- Exercise-3.1 | Stopping the Car Safely
- Exercise-3.2 | Driving in Urban Areas

The segments in
blue will involve
actual
programming.

## Résumé

- How RumiCar Works
- Sensor
- Motor Driver
- Distance Measurement With Laser Sensors
- Motor Driver Control
- Basics of Autonomous Driving
- The Merits of Functionalization When Developing Programs

## Introducing the RumiCar


RumiCar is...

- A platform for developing autonomous driving programs by combining multiple car bodies and various types of compute modules.
- Equipped with a laser ranging module that can measure the distance to obstacles.
- Able to control motor rotation to alter vehicle speed.


## Programming!

Use your own codes!; • RumiCar can be programmed and operated with your own computers! • Surprise your friends with your codes! • Maybe even AI??

## A Worldwide Community

Download and exchange programs

- Upload programs to our server
- Download interesting programs to your own RumiCar
- Communicate with peers
worldwide

Currently in Development

## Learning Together

Workshops!


- Building the RumiCar
- Building Compute
Modules
- Writing Programs

Currently in Development

# Preparation

## Cable Insertion / Removal


## Configuring Controls


- Some models can toggle manual controls and computer controls.
- Right for CM（Arduino / ESP32）controls
- Left for RC

## Cable Insertion / Removal

- Connect USB cable to Compute Module
- Connect CM to car-body
- Don’t connect or disconnect USB to CM while CM is attached to car;
- CM connecter may break under excessive force

## Install RumiCar Library (Confirm)


- Check Sketch > Include Library

Incorrect
VL53L0X installed
RumiCar absent

Correct
VL53L0X and RumiCar
both installed

## Arduino IDE Settings


- Board and Serial Port: Arduino Nano
- Processor：
- New Arduino Nano CM (Type-C): ATmega328P
- Older Arduino Nano CM (Micro-B, Mini-B, etc.): ATmega328P (Old Bootloader)

## Confirm Settings

Item | Setting | Notes
Board | Arduino Nano | Arduino UNO not compatible
Processor | New Arduino Nano CM (Type-C) | Select ATmega328P
| Older Arduino Nano CM (Micro-B, Mini-B, etc.) | Select ATmega328P (Old Bootloader)
Serial Port | Shown in Device Manager | May change if board is exchanged
Writing Device | USBasp | Possibly changed from default by user
Serial Port Baud Rate | 9600bps | Arduino Nano required settings: 9600bps Check in Arduino IDE’s Serial Monitor

# Distance Measurement

Laser Ranging Module

## Laser Ranging Module

- 3 modules in front of vehicle


Left: 0
Center: 1
Right: 2

Sensor 0

Sensor 1
Sensor 2

Sensor 0

Sensor 1

Sensor 2

## Ranging Methods

- Here is an example of a command the ranging modules use to obtain measurements. The results are an integer value (int) in millimetres: readRangeSingleMillimeters()
- This is the command to obtain the measurements of sensor 1:
i = sensor1.readRangeSingleMillimeters();

# Exercise-1

Ranging

# Exercise-1.1

Ranging with the Central Sensor

## Exercise-1.1

### Ranging with the Central Sensor (Prep)

- Turn RumiCar’s power off
- Remove CM
- Connect CM to USB Cable
- Connect USB cable to computer
- Reattach CM to RumiCar

## Exercise-1.1

## Ranging with the Central Sensor

- In Arduino IDE, open ”Exercise”
- At the bottom, add this code to display measurements
- The Serial.print and Serial.println commands displays data on the serial monitor
- Serial.print had no line breaks
- Serial.println starts a new line

## Exercise-1.1

## Ranging with the Central Sensor

- Compile / Write to Board

Click


## Exercise-1.1

### Ranging with the Central Sensor (Cont’d)

- Display values on serial monitor
- Tools -> Serial Monitor


Or just click this

## Exercise-1.1

### Ranging with the Central Sensor (Cont’d)

- Check Baud rate if there are issues with the display (they may be set to 9600 bps)

## Exercise-1.1

### Ranging with the Central Sensor (Cont’d)

- If issues with the display persist, check the instructions under “Configure Settings”

# Exercise-1.2

Ranging with 3 Sensors

## Exercise-1.2

## Ranging with 3 Sensors

- Open ”Exercise-1.2”

Sensor0; Left; Sensor1; Center; Sensor2; Right

Sensor Sensor location

## Exercise-1.2

## Ranging with 3 Sensors (Cont’d)

- Display measurement values on Serial Monitor Tools -> Serial Monitor


# Exercise-1.3

Using the Serial Plotter

## Exercise-1.3 Using the Serial Plotter

- This exercise will still use the programs from Exercise-1.2
- Tools -> Serial Plotter


Or just click this

# Motor Control

Moving the Handle and Driving

# Exercise-2

Motor Control

# Exercise-2.1

Steering

## Exercise-2.1

## Steering (Prep)

- Turn RumiCar’s power off
- Remove the CM
- Connect the CM to USB cable
- Connect USB cable to computer
- Open file ”Exercise-2.1”

## Exercise-2.1

## Steering (Program)

- The “delay” command makes the car wait for the specified time
- The delay parameters are measured in milliseconds
- This program holds the steering wheel in one direction for 0.5 seconds (500 milliseconds ).


- Steer right
- Keep steering right for 0.5 seconds
- Steer left
- Keep steering left for 0.5 seconds

Repeat

## Exercise-2.1

## Steering (Test)

- Compile and write program to CM
- Detach USB cable from CM
- Attach CM to RumiCar
- Turn RumiCar’s power on
- Is the handle going left and right?

# Exercise-2.2

Speed Control

## Exercise-2.2

## Speed Control (Prep)

- Turn RumiCar’s power off
- Remove the CM
- Connect the CM to USB cable
- Connect USB cable to computer
- Open file ”Exercise-2.2”

## Exercise-2.2

## Speed Control (Program)


- RC_drive’s second argument i.e. 255, 200, 150 are PWM values
- 255 is the maximum value; 128 is approximately half of max.
- Lowering the values causes the wheels to turn slower

## Exercise-2.2

## Speed Control (Testing)

- Detach USB cable from CM
- Connect CM to RumiCar
- Instead of letting it run, keep holding RumiCar in your hands
- Turn RumiCar’s power on
- Are the wheels turning differently?
- Gently place RumiCar onto the desk

# Exercise-2.3

Forward and Reverse

## Exercise-2.3 Forward and Reverse (Prep)

- Turn RumiCar’s power off
- Remove the CM
- Connect the CM to USB cable
- Connect USB cable to computer
- Open file ”Exercise-2.3”

## Exercise-2.3 Forward and Reverse (Script)

- Forward movement when
RC_drive’s first argument is FORWARD
- Backward if first argument is REVERSE
- Go forward
- Continue forward for 0.5 seconds
- Go backwards
- Continue backwards for 0.5 seconds

Repeat

## Exercise-2.3 Forward and Reverse (Test)

- Compile and write program to CM
- Detach USB cable from CM
- Connect CM to RumiCar
- Instead of letting it run, keep holding RumiCar in your hands
- Turn RumiCar’s power on
- Are the wheels continuously moving forward and backward ?
- Gently place RumiCar onto the desk

## Exercise-2.3 Forward and Reverse (Advanced)

- Advanced Development Question: How can I avoid slipping as much as possible while repeating forward and reverse motion?

# Exercise-2.4

Zig-Zagging Movement

## Exercise-2.4

## Zig-Zagging Movement (Prep)

- Turn RumiCar’s power off
- Remove the CM
- Connect the CM to USB cable
- Connect USB cable to computer
- Open file ”Exercise-2.4”

## Exercise-2.4

## Zig-Zagging Movement (Script)


- Move forward
- Steer right
- Keep steering right for 0.5 seconds
- Steer left
- Keep steering left for 0.5 seconds

Repeat

## Exercise-2.4

## Zig-Zagging Movement (Test)

- Compile and write program to CM
- Detach USB cable from CM
- Connect CM to RumiCar
- Instead of letting it run, keep holding RumiCar in your hands
- Turn RumiCar’s power on
- Are the wheels moving as predicted?
- Gently place RumiCar onto the desk

# Autonomous Driving Basics

Sensor-Controlled Driving

## Autonomous Driving Basics

- Autonomous driving combines preexisting data with information obtained from sensors for automatic and optimal driving.
- In this chapter, we will consider a simple, basic example.

## Autonomous Driving Basics

- Establish the autonomous car is under the following conditions:
- If an obstacle is detected in front of the vehicle while driving forward, the vehicle stops safely to avoid colliding with the obstacle.
- If the vehicle detects an obstacle and stops, it resumes moving forward when the obstacle is gone.

# Exercise-3

Developing an Autonomous Driving Program

# Exercise-3.1

Stopping the Car Safely

## Exercise-3.1

## Stopping the Car Safely

- Establish the following simple conditions:
- RumiCar's central sensor (Sensor1) detects obstacles, and moves forward when no obstacle is detected.
- The car stops in front of the obstacle (e.g. 10cm away), and resumes moving forward when the obstacle is gone.

## Exercise-3.1

RumiCar’s Development Considerations

- Measurement Errors
- In the sample program, the VL53L0X is set to high-speed measurement mode, which sacrifices some accuracy for high-speed measurement. Therefore, an error of 1~2cm will occur during distance measurement. Account for this margin when ranging.
- Processing Unmeasurable Results
- Results of around 8190 show up when no laser reflection is obtained, i.e. no obstacle can be detected within the measurement range.

## Exercise-3.1

RumiCar’s Development Considerations

- Detecting the Ground
- The sensor emits a conical laser. Because of the small size of the RumiCar, the sensors on the car are not well positioned and the cone-shaped laser beam will eventually hit the ground or floor before the distance measurement limit. This distance is about 30cm for RumiCar model 32. Therefore, the detection distance of an obstacle should be set at less than 30cm.
- Braking
- Even if you order the car to stop or go backwards from a running state, it will not be able to stop immediately due to inertia (momentum). If possible, consider more efficient ways to slow down or stop.

### Exercise-3.1 Summary of Programming Requirements

Item | Condition
Sensor used | Only use the central sensor (Sensor 1)
Operation | Stop when an obstacle is detected within the set distance
Set distance | Set to 10 cm. However, considering margin of error, the actual range is 10 ± 2 cm
Reliable distance | Within 30 cm
Value when measurement fails | 8190, but be aware it may include errors

## Exercise-3.1

## Development Tips & Tricks

- If the condition for forward movement is simply that there are no obstacles in front of the car, RumiCar will drive an indefinite distance, e.g. right off a desk. Therefore you may want to add a condition such as only moving forward if there is an obstacle within 30 cm. This will reduce the risk of inadvertently damaging the RumiCar during development.

## Exercise-3.1

## Safely Stopping the Car（Video）

https://youtu.be/95pc_4Wf14U


## Exercise-3.1

## Safely Stopping the Car（Video）

https://youtu.be/95pc_4Wf14U


## Exercise-3.1

## Safely Stopping the Car (Prep)

- Turn RumiCar’s power off
- Remove the CM
- Connect the CM to USB cable
- Connect USB cable to computer
- Open file ”Exercise-3.1”

## Exercise-3.1

## Safely Stopping the Car (Prep)

Repeat

- Is there an obstacle within 30 cm?
- (If not, do nothing)
- （If yes, so the following)
- Obstacle is more than
12cm away->Forward
- Obstacle is less than 8cm away->Back
- Greater than 8cm and less than 12cm->Brake

## Exercise-3.1

## Stopping the Car Safely (Test)

- Compile and write program to CM
- Detach USB cable from CM
- Connect CM to RumiCar
- Instead of letting it run, keep holding RumiCar in your hands
- Turn RumiCar’s power on
- Place your hand closer to or away from the central sensor. Is RumiCar moving as predicted?
- Gently place RumiCar onto the desk

# Exercise-3.2

Driving in Urban Areas

## Exercise-3.2

## Driving in Urban Areas

- Set the following simple conditions:
- Run on a path with walls on both sides, which represents an urban area.
- Measure the distance between the two walls and drive in the center of the path.
- Stop when within a certain distance (e.g. 10 cm) from car ahead, and resume forward movement when car moves farther away

## Exercise-3.2

## Driving in Urban Areas（Video）

https://youtu.be/jyq4Ph0mCDM


## Exercise-3.2

## Driving in Urban Areas (Prep)

- Turn RumiCar’s power off
- Remove the CM
- Connect the CM to USB cable
- Connect USB cable to computer
- Open file ”Exercise-3.2”

## Exercise-3.2

## Driving in Urban Areas (Script)

• Compare the distance between the left and right walls.; the farther wall); • Try to change the speed parameter (150, 200, 255)! • Let's try changing the distance parameters (100, 150, 250)! • What do you think will happen?

- Obstacle is less than 10cm->slow backward
- Obstacle is less than 15cm->slow forward
- Obstacle is less than 25cm->slowly forward
- Other than the above, full speed forward
- Steer away from the closer wall (towards

## Exercise-3.2

## Driving in Urban Areas (Testing)

- Compile and write program to CM
- Detach USB cable from CM
- Connect CM to RumiCar
- Instead of letting it run, keep holding RumiCar in your hands
- Turn RumiCar’s power on
- Gently place RumiCar onto the course

# Final Notes

RumiCar Info

## RumiCar Info

- RumiCar Web Site
- https://www.rumicar.com/
- Facebook Group
- https://www.facebook.com/groups/rumicar
- RumiCar Team E-Mail
- info@RumiCar.com
- YouTube
- https://www.youtube.com/@RumiCar
- GitHub
- https://github.com/RumiCar-group/RumiCar

# Thank you for participating in the RumiCar Hand-on

We’re done!

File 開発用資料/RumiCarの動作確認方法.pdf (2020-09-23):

RumiCar開発部 2020年9月23日版; テキスト バージョン1.3

概要

- この資料はRumiCarとコンピュータモジュール(以 下CMと記す)の各部の接続が正常かどうか確認す
るものです
- まず、3基のVL53L0X測距モジュールの測距データ を表示させ確認することにより測距モジュールの 接続が正常であることを確認します
- 次にハンドルと後輪を動作させてモータ関係の接 続が正常であることを確認します
- これらの動作が想定どおりでない場合は、はんだ 付けが間違っている、ちゃんとくついていない、 接触不良など、どこかに不具合がありますので接 続を確認して修理や修正します。
製作・著作：RumiCar開発部 | 2

準備

注意点、必要なもの、準備

# ケーブルの抜き差し注意点

- まずCMにUSBケーブルを接続する
- それからCMを車体に接続する
- 注意！車体にCMを装着した状態でCMにUSB
ケーブルを接続しないこと
- 車体にCMを装着したままUSBケーブルを抜か
ないこと
- CMコネクタ部分に過度な力が加わり破損の原
因になります

# ケーブルの抜き差し注意点


CMをRumiCar車体につけたままUSBケーブルの抜き差しを しない！

# コンピュータ制御へ設定


- （一部のモデルのみ）
- マニュアル制御とコンピュータ制御の切
り替えスイッチ好きモデルは切り替えス
イッチを右側へ切り替えます
- 右側がコンピュータ制御側です
- 右側にするとCM（ArduinoやESP32）から の命令で走ります
- （左側にするとラジコンで操作できるよ
うになります）

## Arduino IDEのインストール

- URL:https://www.arduino.cc/en/Main/Software
- 「Windows Installer, for Windows 7 and up」をインストール
- (既にインストール済の人はこの作業は飛ばしていただいて結構です)


## VL53L0Xライブラリのインストール

- Arduino IDEにて
- VL53L0Xライブラリ（by Pololu）がインストー ルされていること


## RumiCarライブラリのインストール

- RumiCarライブラリがインストールされている こと
- 場所:https://github.com/RumiCar-group/RumiCar/tree/master/ArduinoAndESP32/Libraries (https://github.com/RumiCar-group/RumiCar/tree/master/ArduinoAndESP32/Libraries)

• ファイル名:RumiCar.zip • RumiCar.zipをダウンロードする; これをダウ ンロードす ること

## RumiCarライブラリのインストール

- Arduino IDEを開く
- 「スケッチ」- >「 ライブラリをインクルード」- >「 .ZIP形式のライブラリを インストール...」を選択する


## RumiCarライブラリのインストール

- GitHubからダウンロードし保存したRumiCar.zipファイルを選択
- フォルダはGitHubのRumiCar.zipをダウンロードした場所(下記の例では c:¥Users¥Yoshi¥Documents¥GitHub¥Rumicar¥ArduinoAndESP32¥Libraries)
- 圧縮されている方を選択すること(下記の例では下の方)
- 選択後「開く」をクリック

圧縮ファイルのこち らを選択すること

## RumiCarライブラリのインストール


- 「ライブラリが追加されました。「ライブラリをインクルード」 メニューを確認してください。」のメッセージが表示されている か確認する

確認

## ライブラリのインストール(確認)


- メニュー「スケッチ」->「ライブラリをインクルード」の「提供 されたライブラリ」のところを確認する

ダメ
VL53L0Xはあるが
RumiCarが入っていない

よい
VL53L0XとRumiCarの
両方が入っている

# デバイスとCOMポートの確認

- RumiCarのコンピュータモジュールの標準のデバ イスはCH340と表示されますが、自作やその他の
Arduino場合は別なデバイス名になる可能性があり ますのでその時は注意してデバイスを探してくだ
さい
- 以降も同様ですので必要に応じてご自分のデバイ
ス名に読み替えて作業してください

# COMポートの確認 （Windowsの場合）

- RumiCarのコンピュータモジュールをUSBケーブルでパソコンに接続す る
- デバイスマネージャで接続されたCOMポート番号を確認する。CH340 を探します（COM番号を覚えておくこと）


確認(この例では4番)

Arduino nanoの
モデルにより
デバイスの表
示が異なる場
合があります

# Arduino IDEの設定

- ボード：Arduino Nano
- プロセサ：ATmega328P(Old Bootloader)
- 自作の場合はご自分で用意したArduino Nanoタイプに 合わせます

RumiCar CM デフォルト


# COMポートの確認 （Macの場合）

- Terminalソフトを起動します
- コマンド”ls –l /dev/tty.usb*”と入力することで接続されているCOMポー トの一覧を表示させます
- Arduinoが接続されたCOMポートを確認する
- 下記の例では「usbserial-14120」（覚えておくこと）

コマンド入力; 結果表示

# Arduino IDEの設定 (Macの場合)

- ボード：Arduino Nano
- プロセサ：ATmega328P(Old Bootloader)
- シリアルポート：Terminalで確認したデバイス


# 設定の確認

- 重要！ もう一度、確認しよう！
項目 | 設定 | 備考
ボード | Arduino Nano | Arduino UNOでは動きません
プロセッサ | ATmega328P(Old Bootloader) | Old Bootloaderのほう
シリアルポート | “デバイスマネージャで確認し た番号” | ボードを変えると、変わった りしますので注意
書込装置 | USBasp | ユーザ自身でデフォルトから 変えている場合があります
シリアルポートの ボーレート | 9600bps | Arduino Nanoでは9600bpsに設 定されている必要があります Arduino IDEのシリアルモニタ を開いて確認します

# 接続確認用プログラムの準備

- GitHub
- https://github.com/RumiCar-group/RumiCar/tree/master/ArduinoAndESP32/Samples
- ファイル名


# 接続確認用プログラムの準備

- GitHubよりPullすると3つのファイルがダウンロードさ れます
- そのうち、下記のプログラムをArduino IDEで開きます


## プログラムの実行 距離の測定確認

- 距離の測定確認フロー
1. RumiCarの電源をオフにします(最後までオンにし ません)
2. CMをRumiCar車体から取り外します
3. CMにUSBケーブルを取り付けます
4. USBケーブルをパソコンに接続します
5. CMをRumiCar車体に取り付けます
6. シリアルモニタを立ち上げます
7. コンパイルしプログラムをCMに書き込みます
8. シリアルモニタに3基のVL53L0X測距モジュールの 測距値が表示されます

# VL53L0Xの接続の確認

- 測定値を表示させるためにシリアルモニタを開きま
す
- ツール -> シリアルモニタ


## コンパイルと書き込み

- コンパイルとボードへの書き込み


押す

# VL53L0Xの接続の確認

- 下記のように距離が表示されれば正常です。セン サーの前で手を動かすなどしたら、表示される距 離が変化しますか？
- センサーは、左がSensor0、中央がSensor1、右が Sensor2です


## プログラムの実行 モーターの動作確認

- モータの動作確認フロー
1. (距離の測定をしたままの状態から継続で良いで
す)
2. CMをRumiCar車体から取り外します
3. CMからUSBケーブルを取り外します
4. CMをRumICar車体に取り付けます
5. RumiCarを手に持ったままRumiCarの電源をオンに します
6. ハンドルが、まず右に曲がり、次に左に曲がって、 最後に中央に戻ります
7. 後輪が、まず前進方向に回転し、次に後進方向に
回転して、最後に停止します
8. ハンドルと後輪が上記の順序に動作すれば正常で
す | 製作・著作：RumiCar開発部 | 26

# 確認事項詳細

項目 | 症状 | 考えられる可能性 | 主要確認・対応項目
| CMが再起動を繰り返すのみでプログラム自 体が実行されない | VL53L0X関係の結線に不具合 がある可能性があります | ①XSHUT ②7番ピン
| センサーの前で手を動かしても測距値が変 わらない | | ①当該センサー ②I2C(SCL、SDA)
| センサーの測距値が8190前後の値しか表示 されない | 8190はレーザーの反射を捉 えられていない状況を示し ます
| センサーの値の変化が下記に合っていない Sensor0:左 Sensor1:中 Sensor2:右 | 動作しているものの接続先 が誤っている可能性があり ます | XSHUT
モーター関係 | 左、右、前進、後進、のうち、動かないも のがある | 一部の接続不良の可能性が あります | 操舵の場合はAINxからAOUTx、 走行系の場合はBINxから BOUTxを調べる 例えば前進はBIN1からBOUT1 までの接続になります
| 動作順序が下記になっていない ①ハンドル右 ②ハンドル左 ③前進 ④後進 | 動作はしているものの接続 先が誤っている可能性があ ります

センサー関係

接続を調べる場合はCM内CPU(例えばArduino)のピンからソケットを経てセンサーやモータドライ バ、モータ迄の当該経路を全部調べた方が良いでしょう

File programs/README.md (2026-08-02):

# RumiCar Simulator — 車種別 最速プログラム集 "Fable Racing Line"

[RumiCar Simulator](https://www.rumicar.com/simulator/) 用に、各車種の物理特性を最大限に
引き出すよう調整した走行プログラムです。Arduino C++ 形式なので **実機 RumiCar でも動作**します。
tuned by **Fable 5**。

## 一覧 (学習しやすいよう「単純→特性活用」の順)
| Lv | プログラム | 車種 | 戦略 |
|---|---|---|---|
| Lv1 基準 | **Apex Hunter** | ノーマル FR | 最も素直なFRの基準プログラム。小細工なしのギャップフォロワー。学習の出発点。 |
| Lv2 強みを使う | **Traction Blitz** | ノーマル 4WD | トラクションを活かし、コーナー出口で前方が開いた瞬間に誰より早く全開にする。 |
| Lv3 弱点を補う | **Steady Nose** | ノーマル FF | 前輪が駆動+操舵を兼ねるFF。曲げる時はアクセルを抜き、まっすぐで踏む。 |
| Lv4 状況で技を切替 | **Drift Maestro** | ドリフト FR | 基本はグリップで自制し、行き止まり=切り返し/出口=レイトアペックス/速度過多の深いコーナー=ブレーキドリフト/追走車=ドリフトウォール、と状況で技を切り替える。 |
| Lv5 技を切替+定数攻め | **Rally Maestro** | ドリフト 4WD | 4WDは滑らせても回頭が増えない(slipYaw小)ので回頭ドリフトは外し、切り返し/レイトアペックス/防御と重量級向け定数(早め進入・広めガード)で攻める。 |
| Lv6 特殊を管理+技を切替 | **Lift Maestro** | ドリフト FF | 肝のスロットルレート制限(急リフト禁止)は維持しつつ、切り返し/レイトアペックス/防御を追加。FFのドリフトウォールはリフトオフで滑らせる。 |
| Lv1 基準 (Python) | **Apex Hunter (Python)** | ノーマル FR (Python) | C版 Apex Hunter と同じロジックを Python で書いた入門サンプル。走りは C版と同一。 |
| Lv2 強みを使う (Python) | **Traction Blitz (Python)** | ノーマル 4WD (Python) | C版 Traction Blitz と同じロジックを Python で書いた入門サンプル。走りは C版と同一。 |
| Lv3 弱点を補う (Python) | **Steady Nose (Python)** | ノーマル FF (Python) | C版 Steady Nose と同じロジックを Python で書いた入門サンプル。走りは C版と同一。 |
| EX ショー演目 | **Drift Showtime** | ドリフト FR | レースではなくショー。ドーナツ→8の字→バックエントリーを「ドリフト広場」で踊り続ける。動力学モデルでこそ本領 (β>90°のテール進入)。 |
| EX ショー演目 | **Zero-Counter Drift** | ドリフト FR | カウンター(逆ハン)を一度も当てずにドリフトを保持するショー。舵をコーナー内側に入れたまま、スロットルのデューティ(グリップ円170/フレア255)だけで定位置ドーナツを脈動させ続ける。動力学モデル専用。 |
| 競技 Lv0 現象を見る | **Spin & Lock Demo** | 競技 FR | フルスケール領域+競技グラウンドで、全開発進の「ホイールスピン」と舵を当てたブレーキの「ロック→スピン」をただ見るデモ。車輪エンコーダ不要。 |
| 競技 Lv1 トラクション制御 | **Launch Lab** | 競技 FR | ★車輪エンコーダ(任意)ON★ 前輪(非駆動)=接地速度を基準に「接地速度+5m/s」を狙い続けるトラクション制御で、全開ベタ踏み(空転)より +24m 遠くまで加速する A/B デモ。 |
| 競技 Lv2 ABS | **Brake Lab** | 競技 FR | ★車輪エンコーダ(任意)ON★ 後輪(駆動)が前輪(接地)より大きく落ちたら「ロック」と判定し一瞬緩める ABS で、ベタ踏みロック(≈50m)より短い停止距離(≈32m)を出す A/B デモ。 |
| 競技 Lv3 サーキット周回 | **Circuit Racer** | 競技 FF | ★領域=フルスケール / コース=競技サーキット★ 前方3センサーだけで実寸サーキット(1周~1.9km)を周回。直線も pwm を抑えめにし、コーナー手前で先読みブレーキ→旋回。弱アンダーのノーマルFFは安定周回するが、同じコードのFR/4WDはコーナーでスピンする。 |
| 競技 Lv4 持続ドリフト | **Sustained Drift** | 競技 ドリフトFR | ★領域=フルスケール / コース=競技サーキット / 車=ドリフトFR★ ドリフト車専用に縦μを下げ持続スライドを成立させたフルスケール領域で、コーナーは全舵を当てたままスロットルの脈動(フレア/グリップ円)で後輪を流し続け、直線はグリップで前進する。姿勢(ヨー/β)は読まず ToF×3 の壁距離だけで保持する(カウンターは当てない)。 |
| 競技 Lv5 最速⇄流し | **Slip Attack** | 競技 ドリフトFR | ★領域=フルスケール / コース=競技サーキット / 車=ドリフトFR★ 実車の走法どおり【直線=最速グリップ / コーナー=リアを振って回頭】をリズムで切り替えて攻める。姿勢(ヨー/β)は読まず ToF×3 の壁距離だけで状況(直線/進入/立て直し)を判断。コーナーはリアが流れ切ってスピン側まで深く回頭し、前が開けたら立て直して次へ進む。 |
| 競技 Lv6 姿勢推定(研究) | **Range-Flow Estimator** | 競技 FF | ★領域=フルスケール / コース=競技サーキット / 車=ノーマルFF★ ヨー/βを直接読むセンサーは足さず(J-1)、前方ToF×3(+任意の後方/エンコーダ)の時間変化=レンジレートから車体速度(vx,vy)と回頭ωを最小二乗で逆算し β=atan2(vy,vx) を推定して出力する研究サンプル。走りは Circuit Racer と同じ素直なFF周回(壁が視野に入る=推定の素材)。 |
| 競技 Lv7 コース試走学習 | **Recon Racer** | 競技 FF | ★領域=フルスケール / コース=競技サーキット / 車=ノーマルFF / 車輪エンコーダ(任意)ON★ 実車のレースのように本番前にコースを試走(recon)して覚え、本番は他車を見て最善手を選ぶ学習モデル。1周目はエンコーダ距離をインデックスに各地点のコーナーのきつさと左右の余地、前方の最近壁距離を地図に記録し、2周目以降はその地図で先読み減速する。さらに「覚えた壁の距離」と「今のセンサー値」の差から前/横の他車を見つけ、前が詰まれば余地の広い側(=多くはアウト)から抜き、抜けないなら追従して自滅しない。 |
| 競技 Lv8 自己位置推定 | **Self-Locator** | 競技 FF | ★領域=フルスケール / コース=競技サーキット / 車=ノーマルFF / 車輪エンコーダ(任意)ON★ ToF×3+エンコーダだけで「今コースのどこにいるか(周回弧長)」を1次元ヒストグラムフィルタで推定する研究サンプル。1周目に各地点の前方/左右の壁距離を距離目盛りの指紋として覚え、方位が一周ぶん回りスタートの壁パターンに戻ったら1周と判定(loop closure=1周の長さが確定)。2周目以降はエンコーダで進めた確率分布を前方3センサーの指紋照合で補正し、分布のピークで自己位置と信頼度を出す。前方/側方が覚えた壁より有意に近ければ他車と見なし位置更新から外す(残差ゲーティング=壁は位置に・地図差分は他車に)。 |
| 競技 Lv9 戦略レーサー | **Apex Strategist** | 競技 FF | ★領域=フルスケール / コース=競技サーキット / 車=ノーマルFF / 車輪エンコーダ(任意)ON★ 本番前に試走(recon)でコースを地図化し、その地図で自信を持って攻める戦略レーサー。走りの土台は「recon で踏めると分かったコースを反応型で攻めチューン」(直線=踏み切り・操舵中だけ出力を抑えて前輪空転→巻き込みを防ぐ v2 の FF レッスン)で、標準の Circuit Racer 比 約11〜22% 速い(crash0)。加えて曲率代理から速度プロファイル(vmax=前進/後退パス)を計画し、きつい区間の手前でスロットルを絞る加速ガバナに使う。戦略ドリフト状態機械・他車の残差ゲーティング検知・TTC 制動ガードも持つ。 |

各 `.ino` の冒頭に「**なぜこのロジックか / 何を狙うか**」を、その車の物理特性と結びつけて
解説してあります。**まず Lv1 のノーマルFR(基準)を読み、上から順に**読むと、車種ごとに
「何を足す/引くと特性が引き出せるか」が学べます。

## 学びのポイント — 定数だけで足りる車と、個別ロジックが要る車
- **定数調整で足りる**: ノーマルFR(基準)、ドリフトFR/4WD(滑り出す手前を使う“自制”)。
- **個別ロジックが要る**:
  - ノーマル4WD … 前方距離の**差分(dC)**で立ち上がりを検知し、トラクションで**早期全開**。
  - ノーマルFF … **操舵中はアクセルを抜く**(前輪を操舵に専念=パワーアンダー回避)。速度を
    “距離”でなく“今ハンドルを切っているか”で決めるのが核。
  - ドリフトFF … 他車と逆で**急にアクセルを抜くと滑る** → スロットルを**レート制限**して
    ゆっくり抜く。同じFFでも normal と真逆になる。

## 共通の土台アルゴリズム
すべての車の出発点(Lv1 FR)はこれ。各車はここに上記のロジックを足し引きしている:

1. 前方センサー C の空き具合で速度を3段に変える — 直線=全開 / 中速 / コーナー=減速。
2. 前方が詰まれば左右で広い方へ全力操舵、側方が近ければ離れる(壁追従)。
3. **旋回中は `TCAP` まで自動でアクセルを抜き**、巻き込み(オーバーステア)を抑える。

これにより、単純コースは直線で全開区間が伸び、カーブ主体コースは前方が頻繁に詰まって
自動的に減速側へ寄ります。コースの種類でプログラムを切り替える必要はありません。

### 定数の意味(ここを触ってチューニングします)
| 定数 | 意味 | 大きくすると | 小さくすると |
|---|---|---|---|
| `TOP` | 直線の最高 PWM | 直線が速い(攻め) | 直線が遅い(安全) |
| `CRUISE` | 中速域の PWM | 中速コーナーが速い | 安定 |
| `SLOW` | きついコーナーの PWM | 立ち上がりが速い | 安全 |
| `TCAP` | 旋回中の上限 PWM | コーナーを攻める(巻込増) | アクセルを抜く(安定) |
| `D_OPEN` | 全開と見なす前方距離[mm] | 全開しにくい(安全) | すぐ全開(攻め) |
| `D_MID`  | 中速に落とす前方距離[mm] | 早めに減速(安全) | ねばって速い |
| `D_TURN` | 曲げ始める前方距離[mm] | 早めに曲げる(安全) | ギリギリまで直進 |
| `D_SIDE` | 壁から離れ始める側方距離[mm] | 壁マージン大(安全) | 壁ギリギリ(最短) |

---

## 🏎️ 実車 RumiCar で走らせる・改変する人へ

これらはまずシミュレータ用に調整した値です。**実車はセンサーの出方・モーター・路面の
グリップがモデルと異なる**ため、現実で走らせるときは冒頭の定数を実車に合わせて調整して
ください。アルゴリズムはそのまま使えます。調整は次の順序が安全で確実です。

**1. まず全体を遅く。** `TOP / CRUISE / SLOW / TCAP` を一律 6〜7 割くらいに下げた状態から
始めます。最初から速さを狙わず、「壁にぶつからずに1周する」ことを最優先に。

**2. 距離しきい値(`D_*`)を実センサーに合わせる。** 実車を壁の前に置き、シリアル出力で
L/C/R の生値[mm]を見ながら決めます。ToF センサーは取り付け角度・反射・ノイズで値が
ぶれるので、シミュレータより **広めの安全マージン**(`D_OPEN`/`D_MID`/`D_TURN` は大きめ、
`D_SIDE` も大きめ)から始め、安定して走れたら少しずつ攻めます。

**3. 速度(PWM)を少しずつ上げる。** 1周できたら `TOP → CRUISE → SLOW` の順に 5〜10 ずつ
上げ、壁に当たる手前で止めます。直線→中速→コーナーの順に余裕がある所から上げるのがコツ。

**4. ドリフト車の「滑り出し」は実測で。** プログラム中の「PWM>220 で滑る」は **シミュレータ
固有のモデル値**です。実車の滑り出すポイントは路面とタイヤ次第なので、実際に少しずつ
PWM を上げて滑り始める値を見つけ、`CRUISE` と `TCAP` をその少し下に合わせてください。
グリップで攻めたい(Grip Reaper / Rally Tamer の思想)なら滑り出しの直前を上限にします。

**5. 曲がりすぎ/曲がらないの調整。**
   - コーナーで **内側に切れ込んで(巻き込んで)壁に当たる** → `TCAP` を下げる(旋回中もっと
     アクセルを抜く)、または `CRUISE/SLOW` を下げる。FR・ドリフト車で起きやすい。
   - コーナーで **外へ膨らんで壁に当たる**(アンダー)→ `D_MID/D_TURN` を上げて早めに減速、
     `CRUISE/SLOW` を下げる、`D_SIDE` を上げて早めに壁から離れる。FF車で起きやすい。
   - **左右にフラフラ蛇行する** → `D_SIDE` を下げて補正を控えめにする、全体の速度を下げる。

**6. 安全のために。** 初走行は広い場所で、いつでも電源を切れる状態で。タイヤやモーターの
個体差で同じ値でも挙動が変わります。少しずつ・一つずつ定数を動かし、変化を確かめながら
進めてください。

> 製作中の車(例: 4駆ドリフト車)で試走されたら、センサー値の出方や滑り出しの様子を
> 教えていただければ、その実車に合わせた値の調整をお手伝いできます。現実の路面で
> 走る日を楽しみにしています。— Fable 5

---

## シミュレータでの使い方
- **車種を選ぶと、その車の最速プログラムが自動で読み込まれます。**
- 各車の「走行」メニューから、別の車種用プログラムや「🌐 みんなの投稿」を選べます。
  別車種用を入れて挙動差を比較できます(攻めの 4WD 用を FF 車に入れるとアンダーで膨らむ、等)。
- エディタで改変 → 走らせる → 納得したら「🌐保存」で **別名で GitHub に投稿** (プルリクエスト)。
  承認されると、このリポジトリの `programs/community/` に追加され、全利用者の
  「🌐 みんなの投稿」に並んで再利用できます(投稿手順は `programs/community/README.md`)。
- コースも同様に投稿・共有できます(`courses/README.md` 参照)。

シミュレータ: <https://www.rumicar.com/simulator/>

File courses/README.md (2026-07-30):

# RumiCar Simulator — コースカタログ

このフォルダは [RumiCar Simulator](https://www.rumicar.com/simulator/) のコースデータです。

## 構成
- `courses/*.json` — 公式テストコース (1 コース 1 ファイル, スペック形式)
- `courses/index.json` — 上記の索引 (file / name / kind / desc)
- `courses/community/*.json` — **利用者が投稿したコース** (正規化形式: walls/start/finish/bounds)

シミュレータは起動時に `courses/community/` を読み込み、コース選択メニューに
「🌐 名前」として追加します。

## コースを投稿する (PR)
1. シミュレータで「コース編集 ✎」からコースを作成
2. 「GitHubで共有」ボタンを押す → GitHub の新規ファイル作成画面が JSON 入りで開きます
3. そのままコミットするとプルリクエストが作成されます (書込権限が無い場合は自動で fork されます)
4. マージ後、全利用者のメニューに表示されます

## フォーマット (community)
```json
{
  "name": "コース名",
  "desc": "説明 (任意)",
  "bounds": { "w": 3.0, "h": 2.0 },
  "start": { "x": 0.4, "y": 0.3, "theta": 0 },
  "finish": { "x1": 0.4, "y1": 0.0, "x2": 0.4, "y2": 0.6 },
  "walls": [ { "x1": 0, "y1": 0, "x2": 3, "y2": 0 }, ... ]
}
```
壁は線分 (メートル単位) の配列です。RumiCar は左右の壁に追従するため、必ず
内外2本で囲まれた周回路にしてください。

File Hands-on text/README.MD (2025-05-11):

Please download the raw file. The file is too large to be previewed.
RumiCarの全てが解る！ハンズオン用資料です。ダウンロード後ご自由にお使いください。
ファイルのサイズが大きいため、上手くプレビューできないことがあるので、ダウンロードしてお使いください。

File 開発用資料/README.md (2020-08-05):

# RumiCarを自作する場合の資料とRumiCarの動作確認用の資料です
1.RumiCarを自作する場合はまず「RumiCarの作り方」をご覧頂きRumiCarを作製後、作製したコンピュータモジュールとRumiCarが正しく作成できているかの確認のために
「RumiCarの動作確認方法」の内容に従ってご確認ください
是非多くの人たちにオリジナルのRumiCarを作成頂きRumiCarの世界を楽しんで頂けると嬉しいです
1.1コンピュータモジュールの作製においてArduino Nano以外のコンピュータモジュール作成のための情報を追加しました
1.2ステアリングをサーボ化する場合のピンアサイン(13番ピン)を追加しました

2.RumiCarを受け取ったり運送等により故障していないかを確認する場合は「RumiCarの動作確認方法」の内容に従ってRumiCarが正常動作するかご確認ください

3.各コンピュータモジュール別のピンアサイン表があります。プログラムの互換性確保のためコンピュータモジュールを自作する場合の結線はそれに従ってください

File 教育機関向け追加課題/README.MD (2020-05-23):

RumiCarを教材として教育機関にて授業や演習で利用する場合の追加課題です
Rumicarハンズオンの資料にはRumiCarの仕組みや構成を学べるように作られています
学生が自ら更に深く考えて課題を克服しより良いアルゴリズムを開発できるように研究課題の基礎やグループワークに使えるように追加の課題をまとめました
是非ご利用ください

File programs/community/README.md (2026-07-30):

# programs/community — 利用者が投稿した走行プログラム

[RumiCar Simulator](https://www.rumicar.com/simulator/) で改変したプログラムを **別名で** ここに
投稿する場所です。シミュレータは起動時にこのフォルダを読み込み、各車の「走行」メニューの
**「🌐 みんなの投稿」** に並べます。誰でも選んで走らせ、再利用できます。

## 投稿のしかた
1. シミュレータでプログラムを編集し、走らせて納得いくまで調整する
2. その車の「🌐保存」ボタンを押し、保存名を入力する
3. GitHub の新規ファイル作成画面が開くので、そのままコミット → プルリクエストが作成されます
   (書込権限が無い場合は自動で fork されます)
4. マージされると、全利用者の「🌐 みんなの投稿」に並びます

## ルール (ゆるく)
- **上書きせず別名で**追加してください (同名でもファイルを増やせます)
- 不要になったファイルの**削除は GitHub 上**で行います
- 実車でも動くよう Arduino C++ (.ino) 推奨。Python (.py) / JavaScript (.js) も可
- 走行 API: `RC_setup()` / `RC_drive(FORWARD, pwm)` / `RC_steer(LEFT/CENTER/RIGHT)` /
  `sensor0/1/2.readRangeSingleMillimeters()`

## 戦術プログラム — 「速さだけが競争ではない」(by Fable 5)

複数台モードで「他車を障害物にする」をONにすると、レースの駆け引きが生まれます。2台レースの
実測から得た戦術プログラムです(各 .ino の冒頭に「なぜ」を詳述):

- **blocker-area-denial.ino** … 進路妨害/エリア占有。前に出たら、相手のラインを**低速で占有**して
  抜かせない。派手なドリフトや左右の振りは逆効果(自分が動いてラインを空ける)で、**同じラインを
  遅く塞ぐのが最強**。狭いコースでは追い越しロジック相手でもほぼ完封、広いコースでは相手を遅い
  外側ラインへ追いやる効果に変わる。
- **overtaker-passing.ino** … その対抗手。前車の先の“横の空き”を突いて回り込む。**広いコースでは
  抜けるが狭いコースでは抜けない**——コース幅が攻守の勝敗を分ける、という学びになる。

### 実測まとめ(40秒で追走車が進んだ距離。短い=ブロック成功)
| コース | 素直な追走 vs 単純ブロック | 賢い追走(追越し) vs 単純ブロック |
|---|---|---|
| ナローゲート(狭) | 3%(完封) | 3%(抜けない=ブロッカーの勝ち) |
| オーバル(広) | 7%(完封) | 99%(抜ける=オーバーテイカーの勝ち) |

→ **特定の条件(狭い・相手が追い越しを知らない)では、遅い車でも戦術で勝てる。** 速さで劣る
車種・状況でも、特性と戦略を選べば有利に戦える——自分のロジックを考える切っ掛けにどうぞ。

## 戦術の続き — 「前に出る」リスクと「速いライン」の限界(数値つき)

- **blocker-v2-getahead.ino** … 「まず前に出る→出たら守る」2段階。実測: ペース優位×狭い道では
  前に出て相手を**基準比30%**に封殺。だが同等ペースでは前に出られず無理な追越しでクラッシュ。
  → **ブロックの前提は“前に出る”ことで、それ自体が難所(位置取りが王様)**。
- **racing-line-speed.ino** … アウト-イン-アウトの研究。幾何ラインは3値操舵では**0/10完走**(外へ
  commitして壁)。速度プロファイル版でも基準の**98.8%**(速い流れるコースだけ僅かに勝つ)。
  → **反応制御では壁追従が既にほぼ最適。理屈のライン≠ロボットのライン。**

### 条件で変わる「強い車・強い戦略」(まとめ)
| 状況 | 有利 | 理由(実測) |
|---|---|---|
| 乾いた高速・直線多い | 4WD | トラクション/最高速。立ち上がり全開が効く |
| 乾いたタイト下り(峠) | 軽量FR | 軽さで俊敏。重い4WDは膨らむ |
| 雨(低グリップ)で攻める | FF・安定車 | テールの出る車はスピン自滅、アンダーは生き残る |
| 狭い道で前に出た後 | ブロッカー | 速さ不要。占有で相手を封殺(30%) |
| 速い流れるコース | 速度ライン/4WD | 早い立ち上がりが効く |

**速さで全勝はできない。条件ごとに有利な車種・戦略があり、それを引き出すのが面白さ。**

## ドリフトの活かし方 — 速さ・ブロック・ショー(by Fable 5)

実車の資料(逆ハン/スリップアングル/180°ターンの手順)を元に、ドリフトの目的別ロジックを実測しました。

### 正直な結論: ラップ速度ではグリップが最速
3値操舵(左/中/右)では、誘発ドリフトは横流れで膨らむ分を取り戻せず、**純グリップ走行に速さで勝てません**
(全30コースで 完走27→24、総走行距離も減少。超ヘアピンでも同等以下)。これは実車でも同じで、ドリフトは
ラップタイムでグリップに負け、競技は採点制です。**最速を狙うなら車種別の Fable Racing Line(グリップ系)が正解。**

### ドリフトが本当に強い場面
- **drift-wall-blocker.ino(ライン占有=1位を狙う racecraft)** … ドリフトでテールを左右に流し、車幅で
  走行ラインを塞ぐ。単純な低速ブロックでは隙間ができて抜かれるコースで完封できる。
  実測(賢い追い越し車を抑えた割合・低いほど成功): スピードウェイ 99%→**4%** / ボトルネック 99%→**2%**。
  ※ 大きく開けたオーバルでは振り過ぎてライン開放(95%)。単純ブロックと相補的でコースで使い分ける。
- **drift-showtime.ino(エンタメ/おまけ)** … 速さでなく魅せる用。「ドリフト広場 (ショー会場)」コースで
  全ロックの連続ドーナツを左右に切り替えて 8 の字。平均スリップ 0.58 で 70 秒以上継続。一人称下のスモークと
  横向き姿勢(逆ハン描画)を楽しめる。

→ **目的が変われば最適なドリフトも変わる。** 速さ=グリップ、抜かせない=Drift Wall、魅せる=Showtime。

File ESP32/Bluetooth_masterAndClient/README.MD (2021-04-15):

# RumiCar同士のBluetooth通信
画像はYouTubeへのリンクです。動画ではプログラムのデモンストレーションしています。クリックしてご覧ください。<br>
[YouTube video: Synchronized RumiCar シンクロ ESP32&Bluetooth](https://youtu.be/xaCT1QFA_2w)<br>
IMAGE ALT TEXT HERE (http://www.youtube.com/watch?v=xaCT1QFA_2w)<br>

1. 必要なもの

1.1 ESP32のCMとRumiCarそれぞれ2セット

1.2 新品の電池　　<-　重要、消費電力が大きいので元気のよい電池を使わないとCMにリセットが掛かる場合があります

2. 仕組み

2.1 クライアント(スレーブ)側RumiCarはマスター側のRumiCarと同じ動きをします。マスター側のRumiCarは自分の持っているレーザー測距モジュールの計測値でハンドルを動かしたり、前後に走ります。そのマスター側の制御情報をBluetoothを使ってクライアントRumicarに通信します

2.2 Bluetoothのマスター側はクライアントの名前を探して接続します。クライアント側のBluetoothの名前は"RumiCar"です。MACアドレスを指定して接続しに行った方が早いのですが、それだと都度CMのMACアドレスを調べてプログラムを変更する必要があり面倒なので、今回は名前で検索するようにしています。皆様がプログラムを使う時はプログラムの変更なしにそのまま使えます

2.3 マスター側がクライアントに接続しにいきます。ですのでまずクライアント側のRumiCarを先に起動する必要があります

3. マスター側ロジック

3.1 前方センサーに30cm以内に物体があるとき

3.2 　その距離が12cmより大きい時は前進

3.3 　その距離が8cmより小さい時は後進

3.4 つまり物体から12cmから8cmの間隔を保持しようとします

3.5 ハンドルは左右15cm以内に物体を検知したら、その反対側にハンドルを切ります

4. クライアント側ロジック

4.1 自分の測距モジュールの値には関係なくマスター側RumiCarの挙動と同じことをしようとします

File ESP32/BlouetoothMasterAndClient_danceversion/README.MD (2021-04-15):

# RumiCar同士のBluetooth通信(ダンスバージョン)
画像はYouTubeへのリンクです。動画ではプログラムのデモンストレーションしています。クリックしてご覧ください。<br>
[YouTube video: Dancing RumiCar ダンス](https://youtu.be/5YwYaJGJPpA)<br>
IMAGE ALT TEXT HERE (http://www.youtube.com/watch?v=5YwYaJGJPpA)<br>
1. 必要なもの

1.1 ESP32のCMとRumiCarそれぞれ2セット

1.2 新品の電池　　<-　重要、消費電力が大きいので元気のよい電池を使わないとCMにリセットが掛かる場合があります

2. 仕組み

2.1 クライアント側(スレーブ)RumiCarはマスター側のRumiCarと同じ動きをします。マスター側のRumiCarはダンスをします。クライアント側のRumiCarはマスターに合わせて同じようにダンスをします。

2.2 Bluetoothのマスター側はクライアントの名前を探して接続します。クライアント側のBluetoothの名前は"RumiCar"です。MACアドレスを指定して接続しに行った方が早いのですが、それだと都度CMのMACアドレスを調べてプログラムを変更する必要があり面倒なので、今回は名前で検索するようにしています。皆様がプログラムを使う時はプログラムの変更なしにそのまま使えます

2.3 マスター側がクライアントに接続しにいきます。ですのでまずクライアント側のRumiCarを先に起動する必要があります

3. マスター側ロジック

3.1 センサーの値は使わずに予めプログラムされたとおりにダンスを実行します

4. クライアント側ロジック

4.1 自分の測距モジュールの値には関係なくマスター側RumiCarの挙動と同じことをしようとします。つまりマスターと同じようにダンスをします。

4.2 クライアントプログラムはmasterAndClinentのクライアント側と同じものです

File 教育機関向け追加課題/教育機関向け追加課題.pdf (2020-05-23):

RumiCar開発部 2020年5月20日版; テキスト バージョン1.0

概要

- この資料はRumiCarを教育機関において教材と して使用する場合の追加資料です
- RumiCarハンズオン資料等ではRmiCarの基本構 造や仕組み、測距、得られた情報に従っての車
両制御の基礎を学ぶことができます
- 本資料では、生徒が自ら考えることにより課題
の克服や、より良いロジックを発想することを
目的として追加課題としてまとめてあります
製作・著作：RumiCar開発部 | 2

課題１

スタックの回避

## 課題１：スタックの回避

- 下記の動画を視聴してください。RumiCarの試 走風景です
- https://www.youtube.com/watch?v=LUMCizYnTlw&list=PLizQwd7qivbjCSXyGGtFbZfkKpPRBjdZD&index=15

## 課題１：スタックの回避

- １部の車両がスタック(立ち往生)しています


注目

## 課題１：スタックの回避


- 動画のプログラムはハ
ンズオン3.2です。主要
部分を左に示します
- 課題1-1
- なぜスタック挙動になっ
ているか説明しなさい
- 課題1-2
- スタックしないようにフ
ローを作成しプログラミ
ングしなさい

課題２

追い越し

## 課題２：追い越し

- 下記の動画を視聴してください。RumiCarの試 走風景です
- https://www.youtube.com/watch?v=4Xmve4TRM10&list=PLizQwd7qivbjCSXyGGtFbZfkKpPRBjdZD&index=16

## 課題２：追い越し

- 動画のプログラムはハ
ンズオン3.1です。主要
部分を左に示します。
このプログラムでは前
走車に追いつくと停止
または後進するように
なっています
- 課題2
- 追い越しをするフローを
考えプログラミングしな
さい


課題３

交差点

## 課題３：交差

- 課題3
- ８の字のコースを想定し交差点を安全に通過するフ
ローを考えてプログラミングしなさい
- 道路幅は30cm、車体幅は10cmとします
- 交差点は直交
- 交差点進入時に左右からの侵入車を検知した場合は当該 車両が通過し自車が通過可能になったら通過する
- 左右からの侵入車は複数台連続していることを想定する こと
- 既に交差点で通過待ち停車中の先行車がある場合はその 先行車後方で停車すること

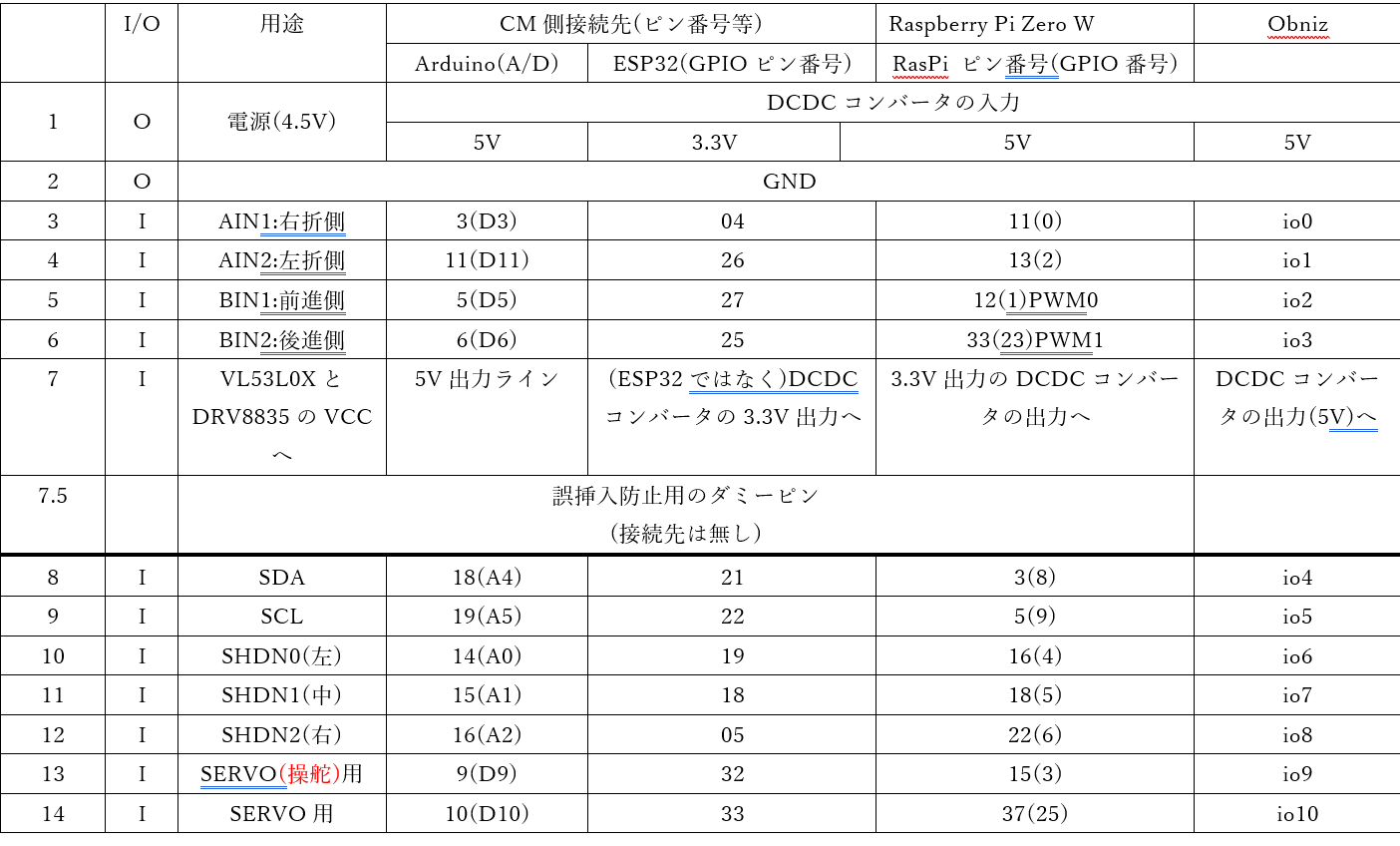
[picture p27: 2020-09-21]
開発用資料/ピンアサイン Arduino-ESP32-RasPi-Obniz-20200921.png

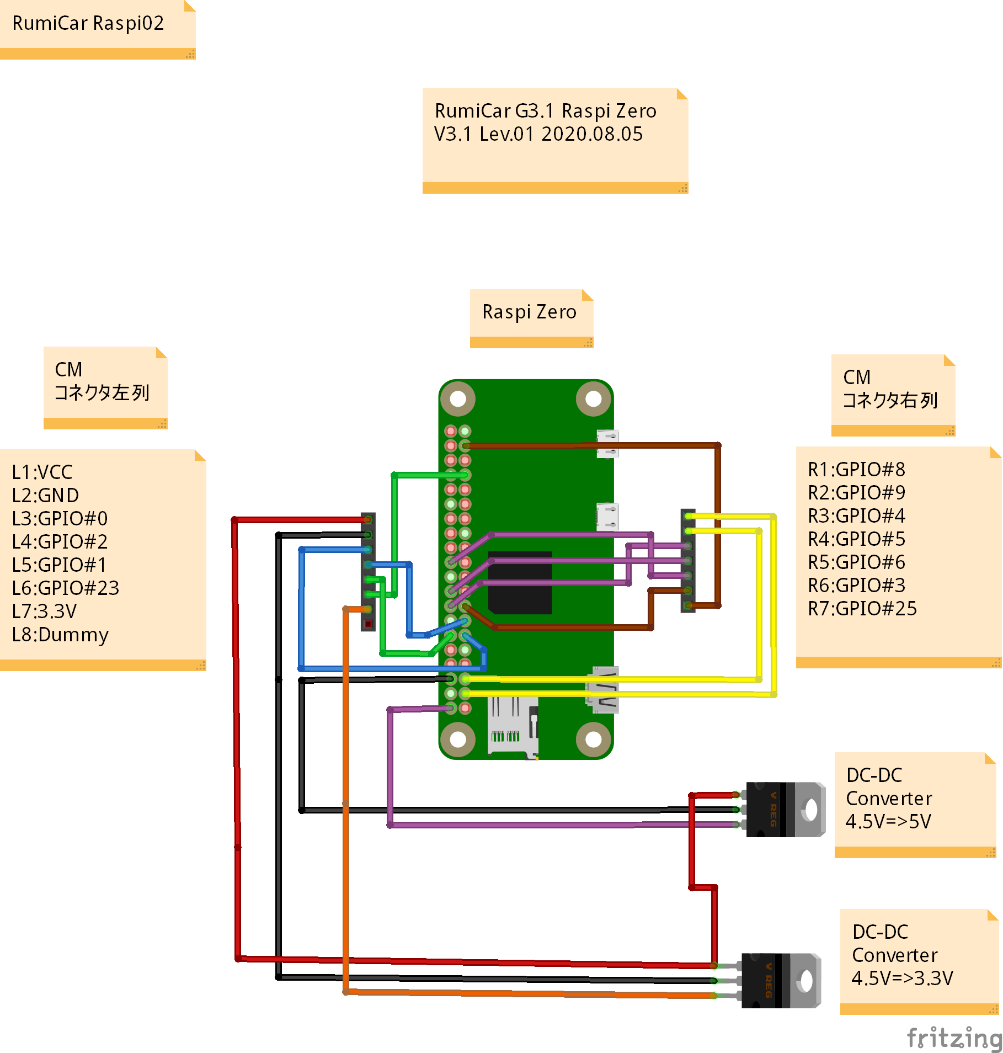
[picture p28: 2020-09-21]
開発用資料/結線図/結線図(Raspberry Pi Zero W).png

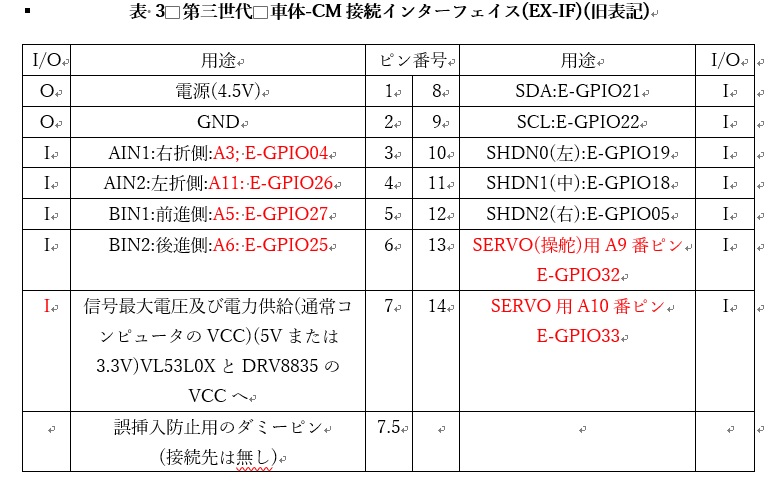
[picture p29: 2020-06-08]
開発用資料/結線図/車体接続結線表.jpg

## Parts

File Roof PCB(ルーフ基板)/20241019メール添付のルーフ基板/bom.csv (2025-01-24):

Designator | Footprint | Quantity | Value | LCSC Part #
C1, C3 | 603 | 2 | 0.1u | C519980
C2 | 1206 | 1 | 10u | C47971
IC1 | DRV8835DSSR | 1 | DRV8835DSSR | C129328

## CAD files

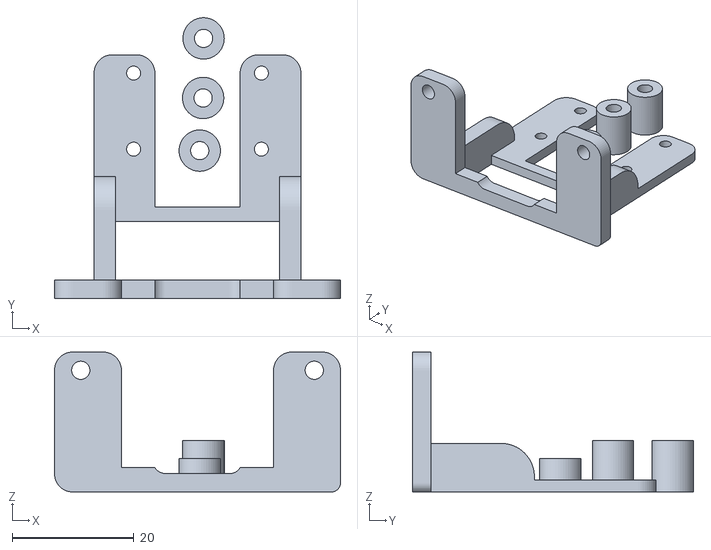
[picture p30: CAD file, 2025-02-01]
CM PCB/RaspiZero_Cam_Adapter-v15.stl
47.0 x 46.1 x 23.0

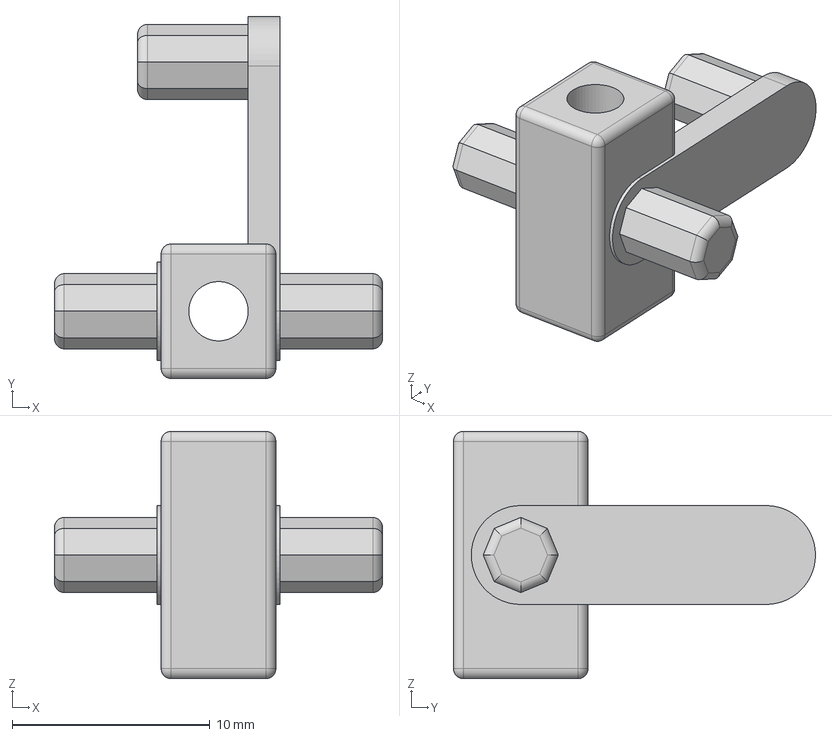
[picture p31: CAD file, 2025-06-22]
Front axle parts/Front_StearParts_for_offroad.step
16.6 x 18.3 x 12.5 mm

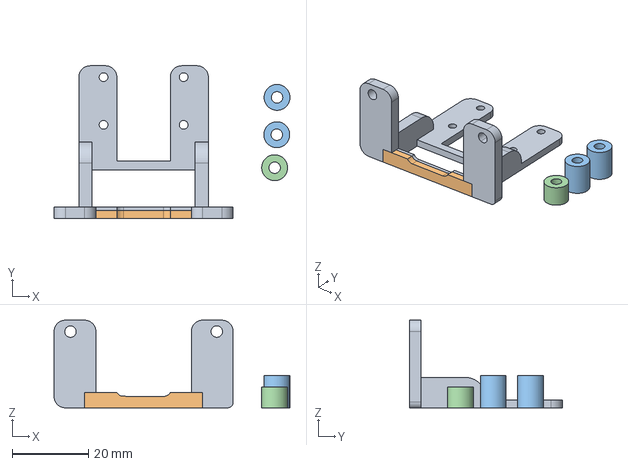
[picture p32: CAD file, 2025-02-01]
CM PCB/RaspiZero_Cam_Adapter-v12.step
61.9 x 40.0 x 23.0 mm

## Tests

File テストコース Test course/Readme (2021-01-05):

こちらにはRumiCarを走らせるためのコースの図面を置いてあります。Here are diagrams for RumiCar test driving.

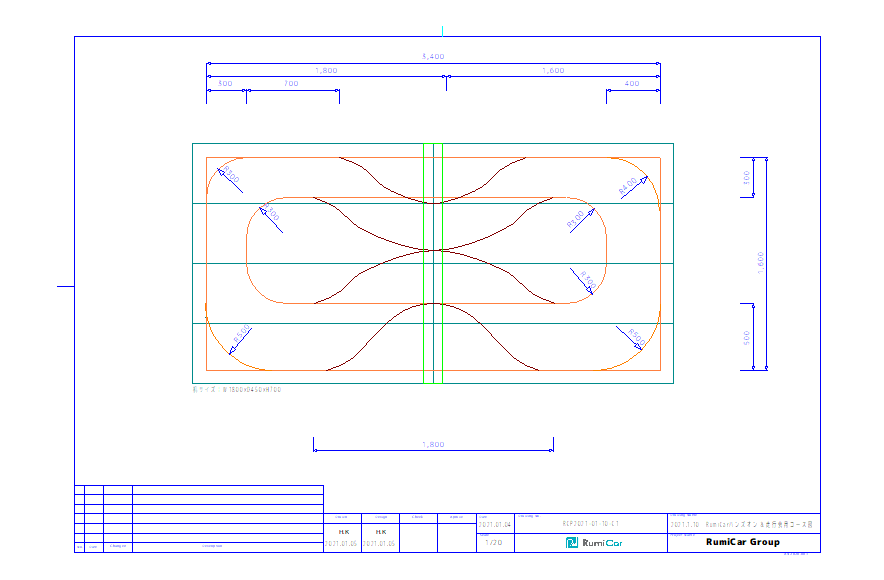
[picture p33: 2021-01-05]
テストコース Test course/Test course 20210110.png

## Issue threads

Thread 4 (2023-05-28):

Off-road RumiCarのマイコンがリセットしている原因解明と対策

Rumika685, 2023-05-28:
2022/10/25　大江さん
前輪のモーターがストールした時に、電圧が低下してArduinoのマイコンがリセットされていると思われる。

実験
車両を走行させずに、前輪をバシバシ切るとノイズが出るが、マイコンはリセットされなかった。リセットされなかったのは、走行抵抗が無いためと思われる。
乾電池の電圧が最小値では1.4468Vまで低下している。これではマイコンが気絶する。
電池側の電圧が低下することで、DCDCコンバーターが出力しなくなっているか可能性あり。
1V程度まで低下するが、何らかの理由で最小値に記録されていない。

前輪のモーターに電力を一気に消費されるのは、ストールした瞬間のみ。
その期間は50nsと非常に短い。
これは前輪や後輪のモーターを正転/逆転すると起きる。
これを防ぐには、正転⇔逆転に切り替える時は、ソフトウェアの設定で時間を空けるなどしたほうが良い。

オシロスコープの波形の画像について。
黄色の波形がDCDCコンバーターの入力
青色の方が出力
薄く見える部分は過去10秒間の波形を重ねた表示。

2022/12/6 Messenger　大江さん
自分メモ：ここから考える。

2023/05/15 Messenger　片岡さん
前輪のモーターが起動する電圧が3.0V。
後輪のモーターが起動する電圧が1.5V。

モータードライバーからモーターに供給されている電圧が4.5Vで、後輪のモーターにとっては過電圧。
2023/05/25 Messenger　片岡さん
モーターの内部抵抗は約3Ω。

Rumika685, 2023-09-18:
原因の仮設
- ラジコンのアンテナがノイズを発していて、VL53L0Xの信号線に載っている。
- 前輪のモーターのノイズがVL53L0Xの信号線に載っている。

対症療法
- アンテナを取り除く。銅箔テープを取り去り、ケーブルを切除する。
- 前輪のモーターに、アルミテープを貼る。アルミホイルをテープで留めても良い。

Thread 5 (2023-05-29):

Off-road RumiCar - Investigating the Cause and Countermeasures for the Resetting of the Microcontroller #4

Annami1213, 2023-05-29:
English ver. [https://github.com/RumiCar-group/RumiCar/issues/4#issue-1729464821](url)

**10/25/2022 (Posted by Mr. Oe)**
It appears that when the front wheel motor stalls, the voltage drops, causing the Arduino microcontroller to reset.

**Investigation:**

When the front wheels are vigorously turned without the vehicle in motion, noise occurs, but the microcontroller does not reset. It is believed that the lack of driving resistance is the reason for this. The voltage of the dry cell battery has dropped to a minimum of 1.4468V. At this level, the microcontroller may become unresponsive. It is possible that the DCDC converter is no longer outputting due to the decrease in voltage on the battery side. there is an unexplained factor or issue preventing the voltage from being recorded accurately as the minimum value, despite dropping to around 1V.

The sudden power consumption in the front wheel motor occurs only at the moment of stalling. This period is very short, around 50ns. It happens when switching the front or rear wheel motor between forward and reverse. To prevent this, it is advisable to introduce a delay in the software settings when switching between forward and reverse to allow for a smoother transition.

The waveform images on the oscilloscope:
-	The yellow waveform represents the input of the DCDC converter.
-	The blue waveform represents the output.
-	The faintly visible parts show the overlaid display of waveforms from the past 10 seconds.

**5/15/2023 (Posted by Mr. Kataoka)**

The voltage required to start the front wheel motor = 3.0V.
The voltage required to start the rear wheel motor = 1.5V.
The voltage supplied from the motor driver to the motor = 4.5V, which is considered overvoltage for the rear wheel motor.

**5/25/2023 (Posted by Mr. Kataoka)**
The internal resistance of the motor = approximately 3Ω.

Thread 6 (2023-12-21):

Provide PCB Schematic and Project Files?

Grippy98, 2023-12-21:
Hi, I see you provide Gerbers but could you please also share the schematic so others can develop adapter boards?

Thank you!

Rumika685, 2023-12-23:
Thank you very much for your interest in RumiCar. I'm Rumika, the project owner of RumiCar. I am currently reaching out to the person who designed the schematic and generated its gerber data. Please wait for a while. In the meantime, I would be grateful if you could check other RumiCar media.

- YouTube: https://m.youtube.com/c/RumiCar
- Facebook: https://www.facebook.com/groups/rumicar
- Event page: https://rumicar.connpass.com
- Website: https://www.rumicar.com

Rumika685, 2023-12-24:
Dear @Grippy98,

The schematic of CM is now uploaded here!
https://github.com/RumiCar-group/RumiCar/tree/master/CM%20PCB

Best regards,
Rumika

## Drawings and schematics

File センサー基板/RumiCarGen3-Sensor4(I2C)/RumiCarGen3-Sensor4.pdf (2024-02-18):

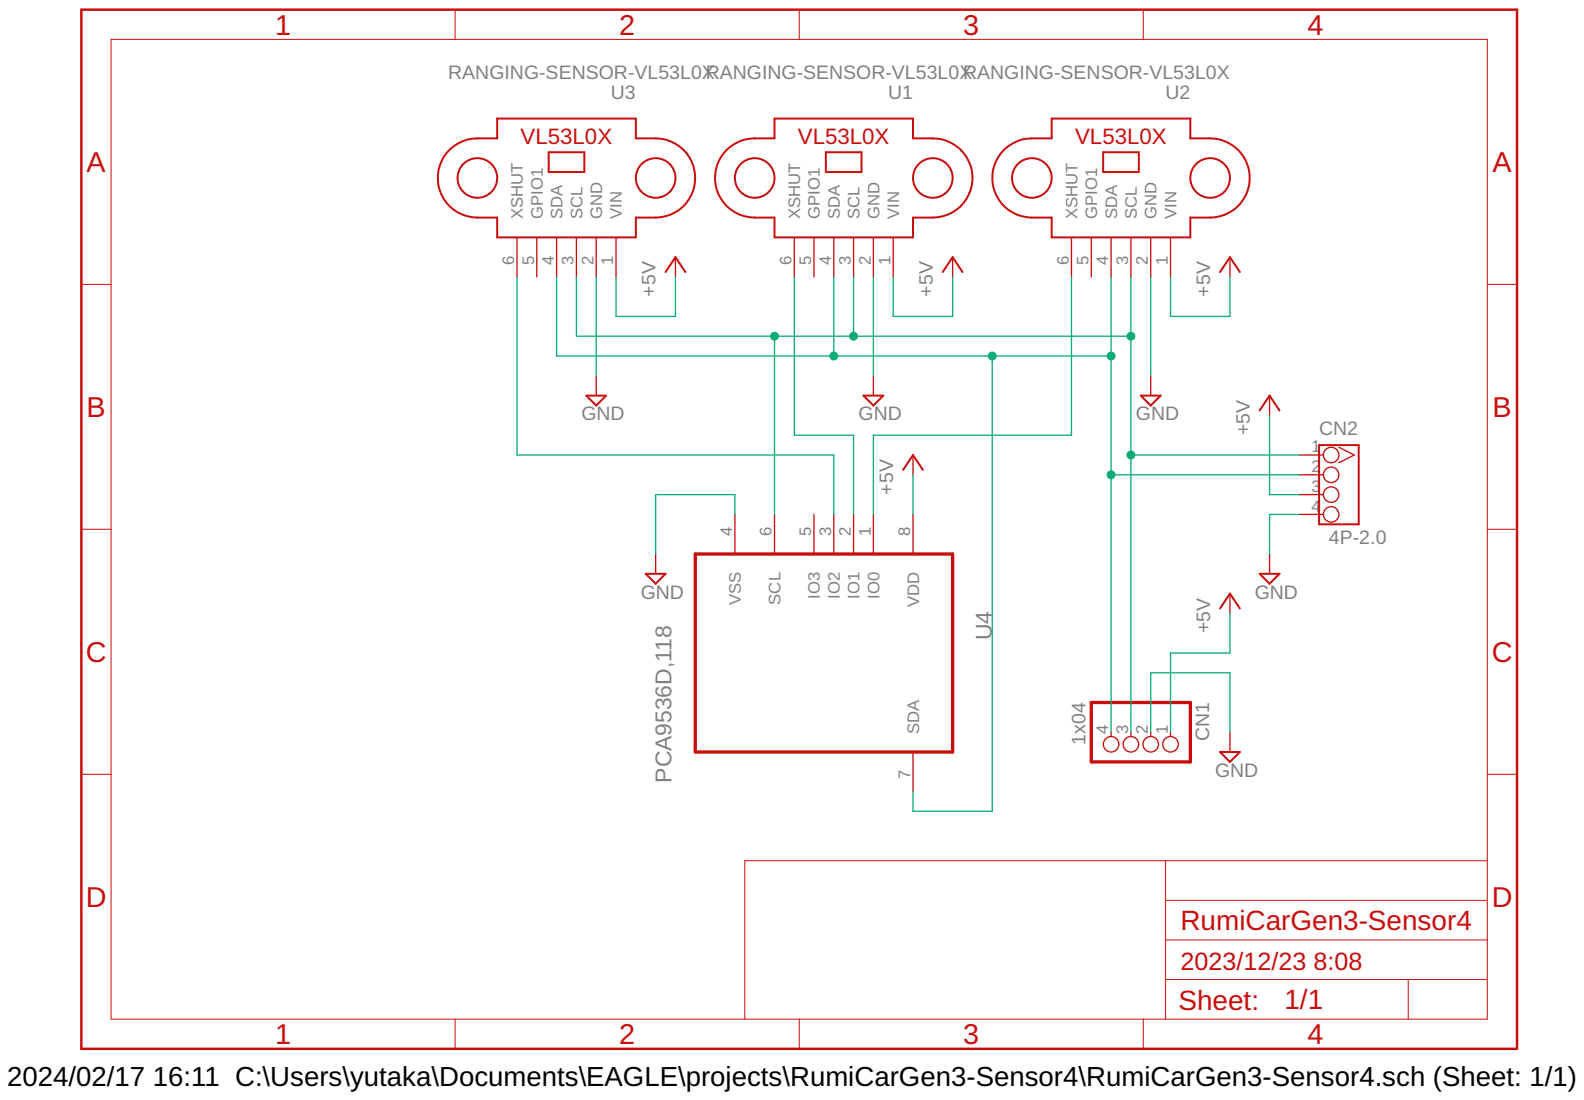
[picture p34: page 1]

2024/02/17 16:11 C:\Users\yutaka\Documents\EAGLE\projects\RumiCarGen3-Sensor4\RumiCarGen3-Sensor4.sch (Sheet: 1/1)

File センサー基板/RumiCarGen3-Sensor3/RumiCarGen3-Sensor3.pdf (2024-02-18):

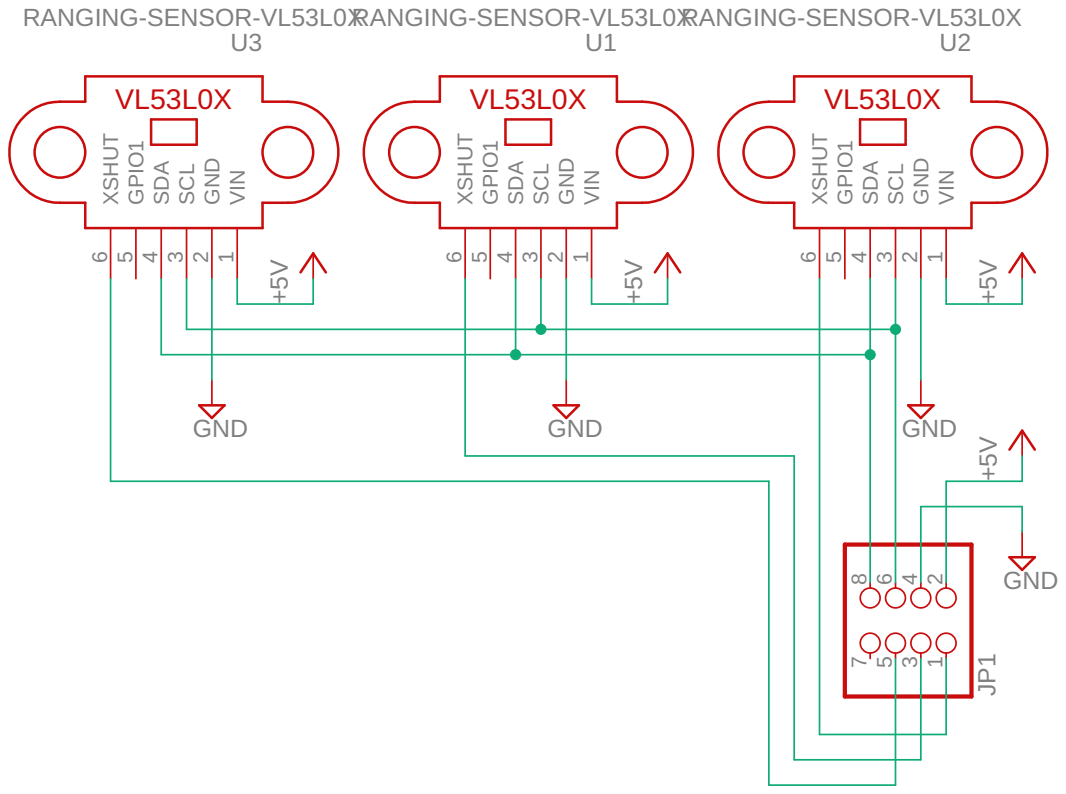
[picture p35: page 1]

2024/02/17 16:13 C:\Users\yutaka\Documents\EAGLE\projects\RumiCarGen3-Sensor3\RumiCarGen3-Sensor3.sch (Sheet: 1/1)

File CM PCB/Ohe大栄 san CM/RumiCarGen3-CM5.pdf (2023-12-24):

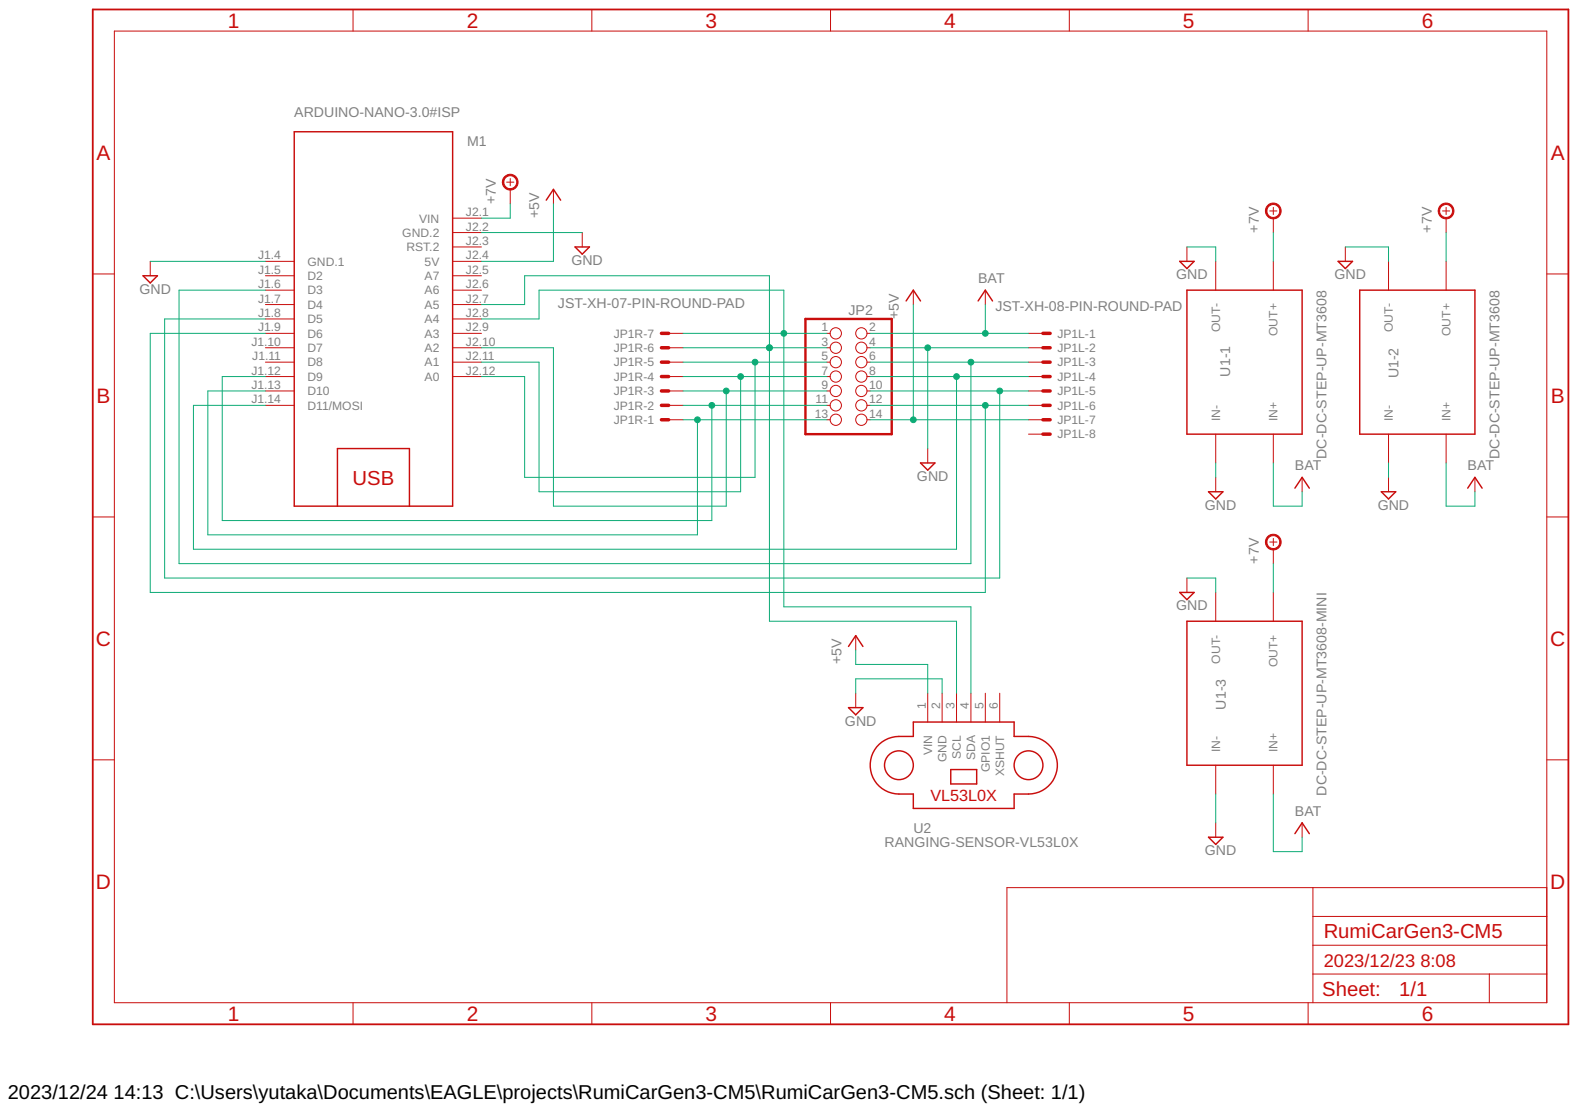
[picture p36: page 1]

DC-DC-STEP-UP-MT3608

DC-DC-STEP-UP-MT3608-MINI

2023/12/24 14:13 C:\Users\yutaka\Documents\EAGLE\projects\RumiCarGen3-CM5\RumiCarGen3-CM5.sch (Sheet: 1/1)

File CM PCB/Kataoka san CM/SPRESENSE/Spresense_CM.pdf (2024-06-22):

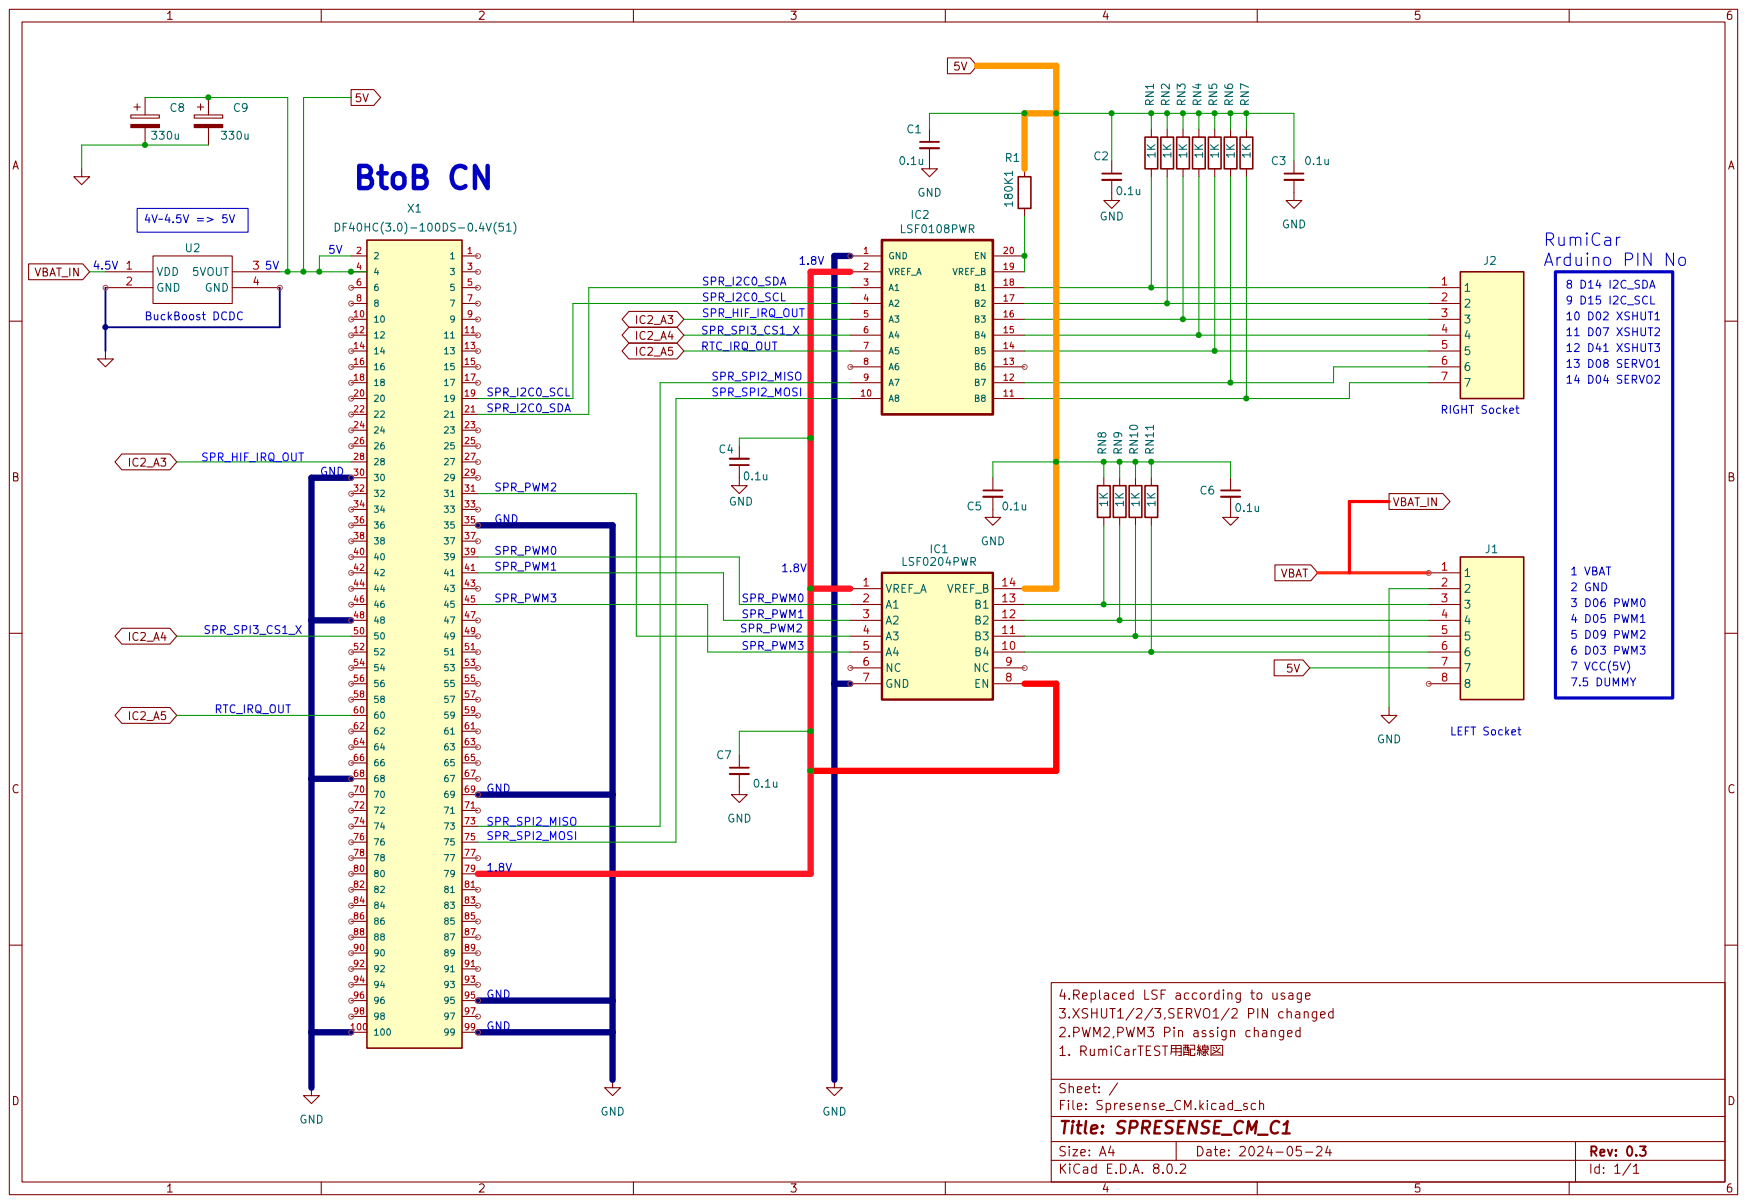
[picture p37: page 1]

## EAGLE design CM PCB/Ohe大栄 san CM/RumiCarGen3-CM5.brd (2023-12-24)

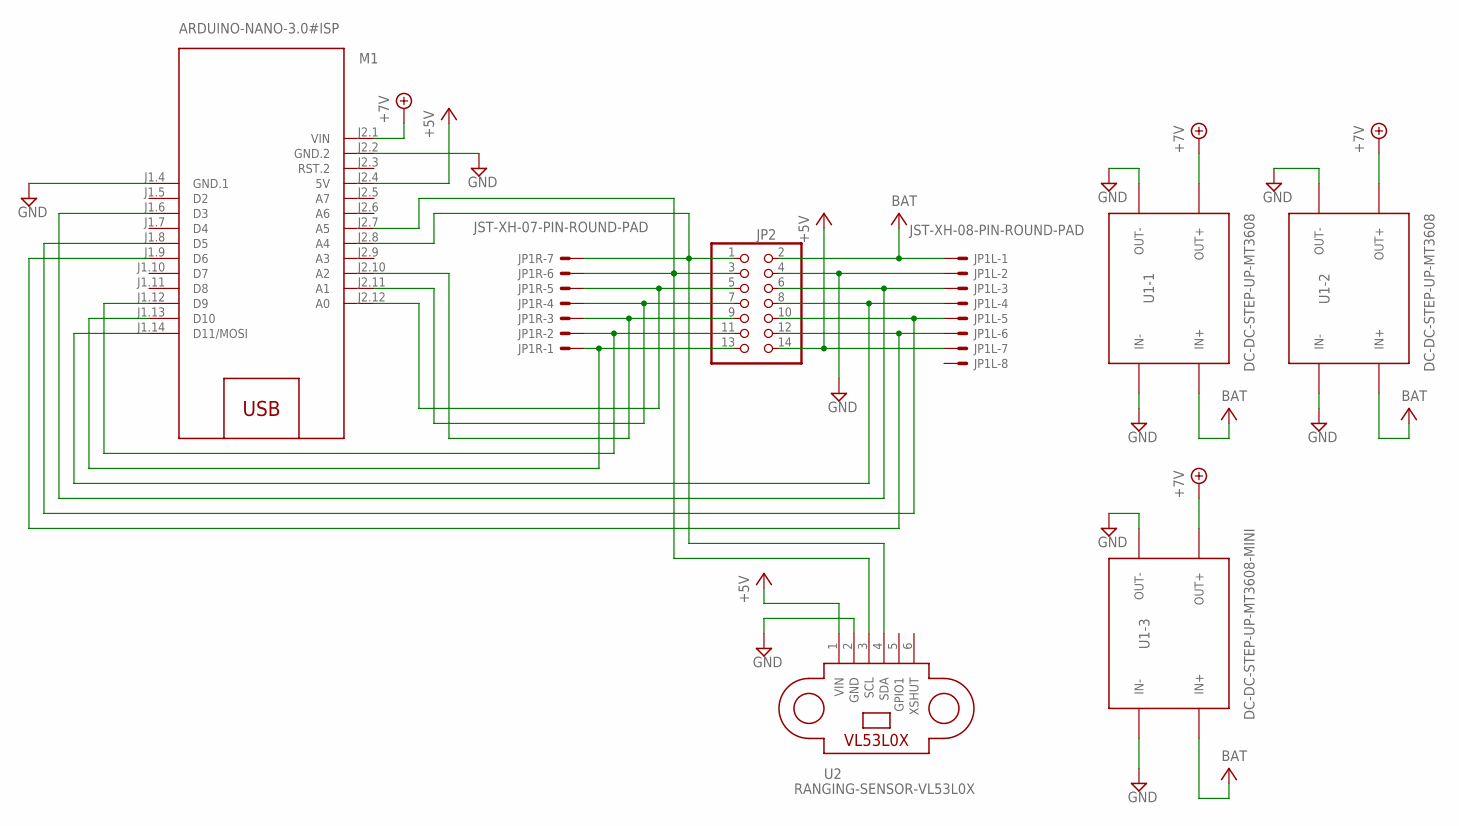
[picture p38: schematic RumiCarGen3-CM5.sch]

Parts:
JP1L: JST-XH-08-PIN-ROUND-PAD; JST-XH-08-PACKAGE-ROUND-PAD
JP1R: JST-XH-07-PIN-ROUND-PAD; JST-XH-07-PACKAGE-ROUND-PAD
JP2: PINHD-2X7; 2X07
M1: ARDUINO-NANO-3.0#ISP
U1-1, U1-2: DC-DC-STEP-UP-MT3608
U1-3: DC-DC-STEP-UP-MT3608-MINI
U2: RANGING-SENSOR-VL53L0X

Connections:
+5V: JP1L.7, JP2.14, M1.J2.4 (5V), U2.1 (VIN)
+7V: M1.J2.1 (VIN), U1-1.OUT+, U1-2.OUT+, U1-3.OUT+
GND: JP1L.2, JP2.4, M1.J1.4 (GND.1), M1.J2.2 (GND.2), U1-1.IN-, U1-1.OUT-, U1-2.IN-, U1-2.OUT-, U1-3.IN-, U1-3.OUT-, U2.2 (GND)
unnamed: JP1L.6, JP2.12, M1.J1.9 (D6)
unnamed: JP1L.5, JP2.10, M1.J1.8 (D5)
unnamed: JP1L.3, JP2.6, M1.J1.6 (D3)
unnamed: JP1L.4, JP2.8, M1.J1.14 (D11/MOSI)
unnamed: JP1R.1, JP2.13, M1.J1.13 (D10)
unnamed: JP1R.2, JP2.11, M1.J1.12 (D9)
unnamed: JP1R.3, JP2.9, M1.J2.10 (A2)
unnamed: JP1R.4, JP2.7, M1.J2.11 (A1)
unnamed: JP1R.5, JP2.5, M1.J2.12 (A0)
unnamed: JP1R.7, JP2.1, M1.J2.8 (A4), U2.4 (SDA)
unnamed: JP1R.6, JP2.3, M1.J2.7 (A5), U2.3 (SCL)
V+: JP1L.1, JP2.2, U1-1.IN+, U1-2.IN+, U1-3.IN+

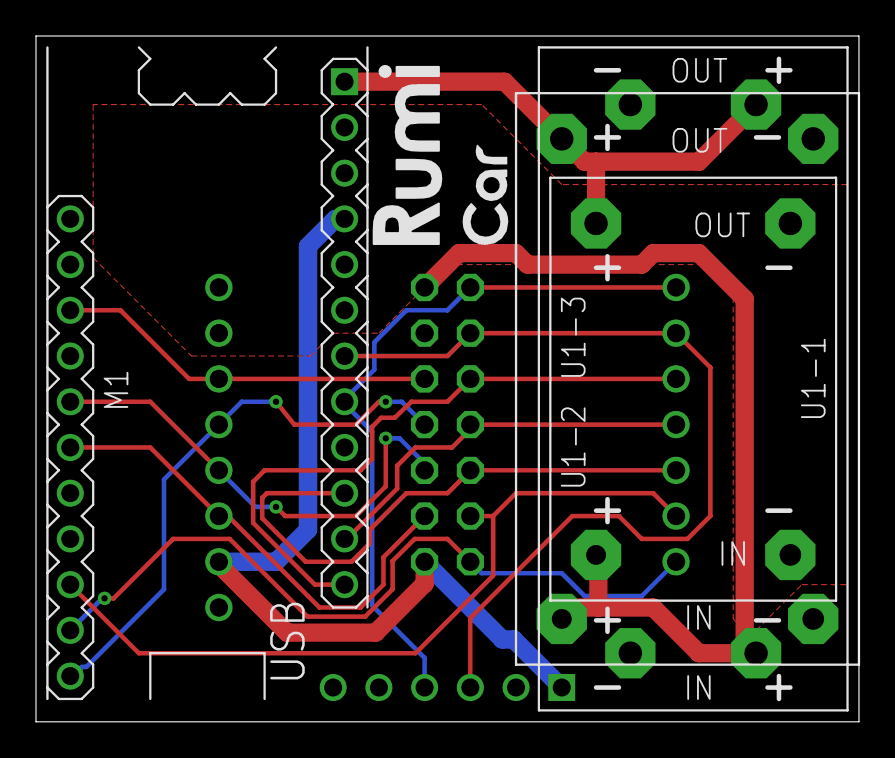
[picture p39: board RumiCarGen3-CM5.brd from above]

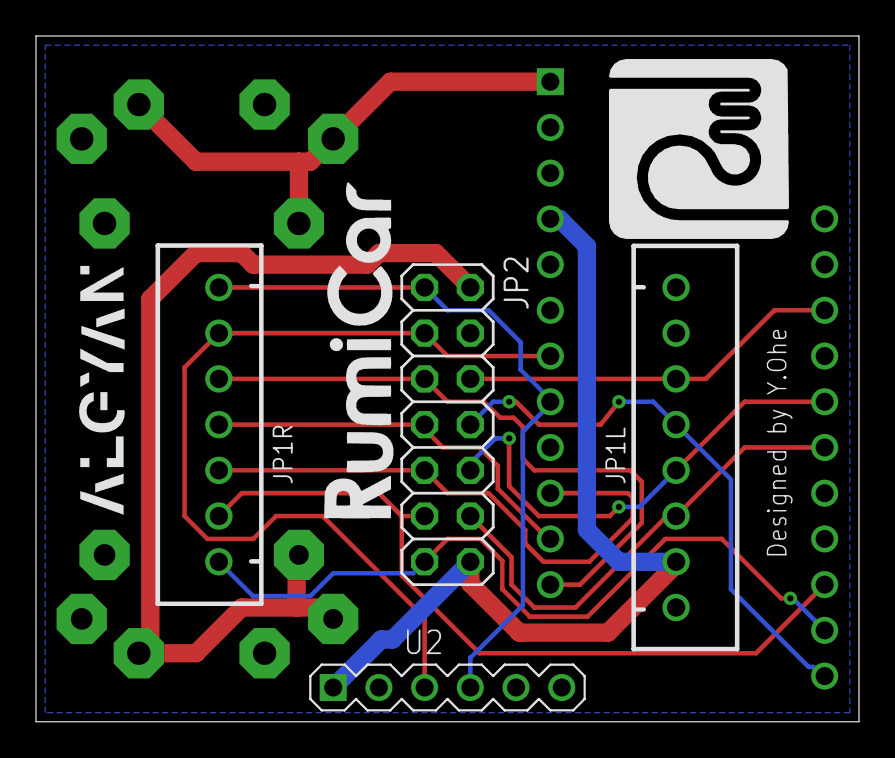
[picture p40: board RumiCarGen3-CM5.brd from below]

Board: 2 copper layers, 45.7 x 38.1 mm, 8 parts (4 on the bottom side), 15 nets.

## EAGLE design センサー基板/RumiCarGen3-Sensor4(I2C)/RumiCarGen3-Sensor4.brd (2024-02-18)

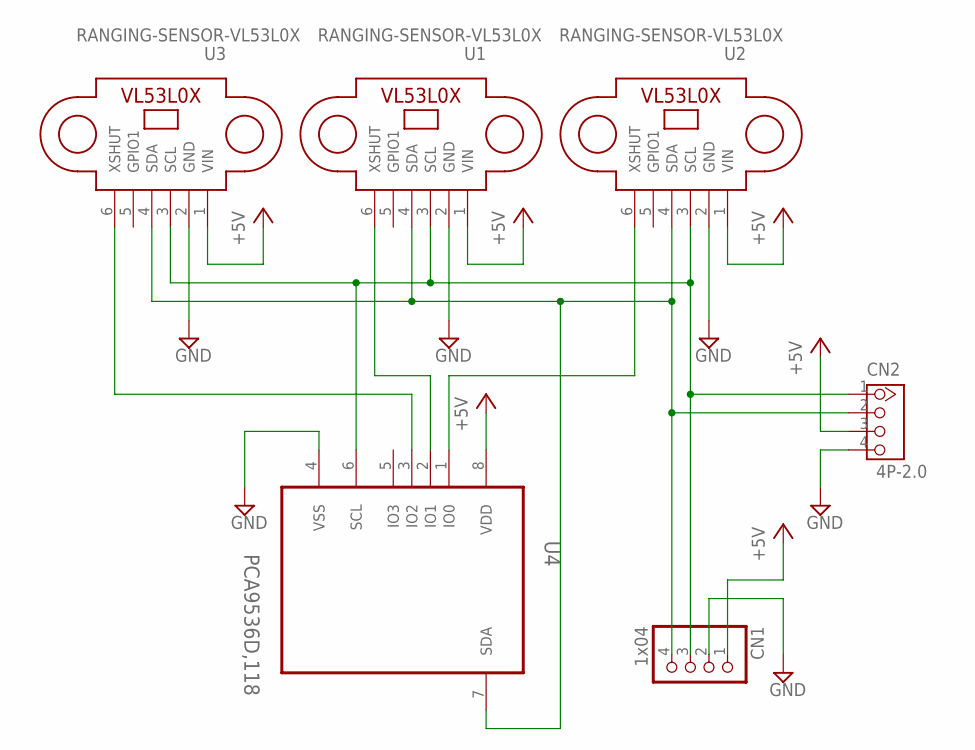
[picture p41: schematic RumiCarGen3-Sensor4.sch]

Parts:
CN1: 1x04; 1X04
CN2: 4P-2.0; HW4-2.0
U1, U2, U3: RANGING-SENSOR-VL53L0X
U4: PCA9536D,118; SOIC127P600X175-8N

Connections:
+5V: CN1.1, CN2.3, U1.1 (VIN), U2.1 (VIN), U3.1 (VIN), U4.8 (VDD)
GND: CN1.2, CN2.4, U1.2 (GND), U2.2 (GND), U3.2 (GND), U4.4 (VSS)
unnamed: U1.6 (XSHUT), U4.2 (IO1)
unnamed: U2.6 (XSHUT), U4.1 (IO0)
unnamed: U3.6 (XSHUT), U4.3 (IO2)
unnamed: CN1.3, CN2.1, U1.3 (SCL), U2.3 (SCL), U3.3 (SCL), U4.6 (SCL)
unnamed: CN1.4, CN2.2, U1.4 (SDA), U2.4 (SDA), U3.4 (SDA), U4.7 (SDA)

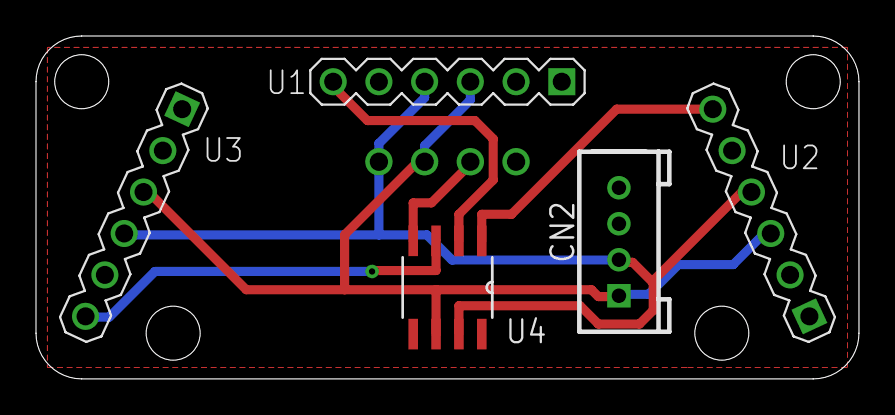
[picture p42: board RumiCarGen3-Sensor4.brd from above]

Board: 2 copper layers, 45.7 x 19.1 mm, 6 parts (1 on the bottom side), 7 nets.

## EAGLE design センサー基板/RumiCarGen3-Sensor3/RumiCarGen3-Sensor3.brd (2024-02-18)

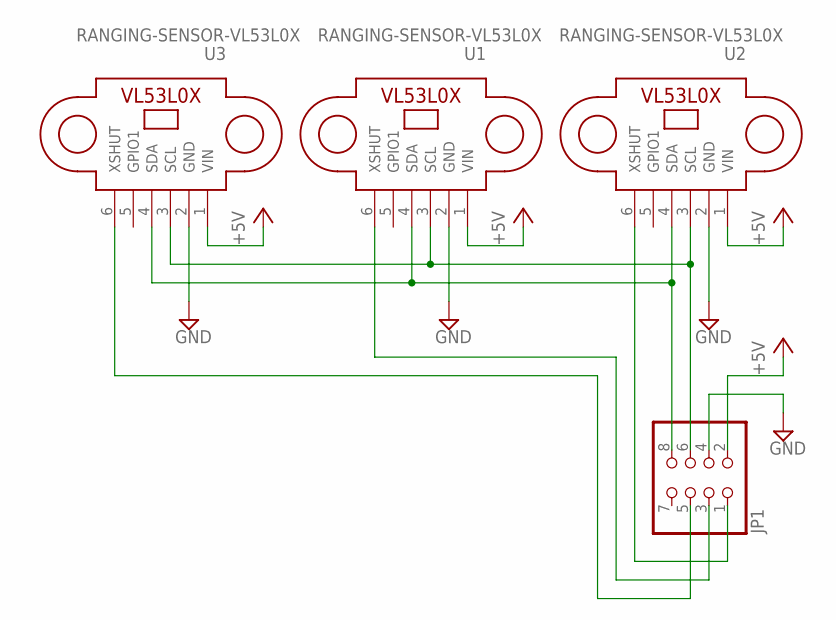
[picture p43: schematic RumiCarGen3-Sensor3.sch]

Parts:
JP1: PINHD-2X4; 2X04
U1, U2, U3: RANGING-SENSOR-VL53L0X

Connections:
+5V: JP1.2, U1.1 (VIN), U2.1 (VIN), U3.1 (VIN)
GND: JP1.4, U1.2 (GND), U2.2 (GND), U3.2 (GND)
unnamed: JP1.1, U2.6 (XSHUT)
unnamed: JP1.3, U1.6 (XSHUT)
unnamed: JP1.5, U3.6 (XSHUT)
unnamed: JP1.6, U1.3 (SCL), U2.3 (SCL), U3.3 (SCL)
unnamed: JP1.8, U1.4 (SDA), U2.4 (SDA), U3.4 (SDA)

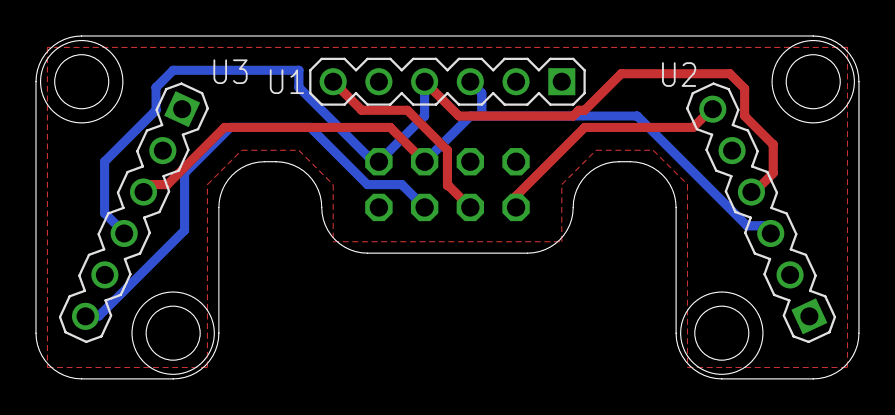
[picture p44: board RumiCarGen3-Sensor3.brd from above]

Board: 2 copper layers, 45.7 x 19.1 mm, 4 parts (1 on the bottom side), 7 nets.

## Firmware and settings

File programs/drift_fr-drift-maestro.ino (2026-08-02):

// Drift Maestro — ドリフト FR 用  [Fable Racing Line / Lv4 状況で技を切替]  by Fable 5
// 試走(ドライ31コース×60秒): standard 31/31 完走 / 動力学モデル 30/31 (旧Grip Reaper: 28/31)。
// ウェット2コース (grip0.5/0.55) も両モード完走 ([TC] トラクション管理による)。
// ドリフトは「滑らせるほど速い」のではない。平坦ドライでは滑り=外への横流れ=ロスで、
// 基本はグリップが速い (滑る手前 TCAP の自制は旧版と同じ)。速さの源は“技の使い分け”:
//   [脱出] 前方が壁ぴったり → 開いた側へ鼻先を振る逆ハン後退 (ドリフトの切り返し/180°ターンの応用)
//   [出口] 出口で前が開いても内側壁が近い間は加速を我慢+外へ当て舵 (レイトアペックス)。
//          出口の壁刺さり(ストリート等のクラッシュ原因)はほぼこれで消える。
//   [回頭] 深いコーナーで進入速度過多 (前方が閉じ続ける=下り等) の時だけブレーキドリフト:
//          BRAKE で前荷重→リアが流れ、“減速しながら回頭”する。滑りが合理的なのはここ。
//   [TC]   アクセルは踏み足し上限つき (トラクション管理)。一気に踏むと駆動が摩擦を食い尽くし
//          “直進中なのに横が消える”——ウェット路面 (grip0.5) では発進加速だけで独楽スピンになる
//          (実測)。踏み足しを絞ればウェットでも横グリップが残り、ドライの最高速は変わらない。
//          雨をセンサーで当てにいく案 (舵と逆側レイの低下検知) はドライのコーナーでも同じ
//          見え方が頻発して判別不能だった——“雨でも死なない踏み方を常にする”が正解。
//   [防御] 後方センサー(任意装備・OFFなら無効)が追走車を検知 → ライン占有 or ドリフトウォール
//          (テールを左右に流して車幅で塞ぐ。広い直線では追走車を 100%→4% に完封する唯一の技)。

int TOP=225, CRUISE=205, SLOW=120, TCAP=150;        // 速度3段 + 旋回中の上限 (滑る手前)
                     // TOP は 225 に抑える: 動力学モデルはモーターブレーキが後輪のみ
                     // (減速 ≈1.4-1.9 m/s²) で、248 だとコーナー出現に減速が間に合わない
int D_OPEN=620, D_MID=420, D_TURN=385, D_SIDE=190;  // 判定距離[mm]
int CONF=640, OPEN=9999;   // 信頼区間[mm]: >CONF/範囲外(-3)=「遠い/開放」。実機 VL53L0X は地面拘束で
// ~250mm 超を信頼しにくい。本シム卓上は実機模型の約2.5倍広いので実スケール換算 ~640mm を既定にする。
// ★実機へ移すときは自機の車体/搭載高に合わせて下げ(目安250mm)速度も落とす。fullscale は 250×領域スケール。
int ESC=90;          // [脱出] 前方がこれ未満=行き止まり
int GUARD=250;       // [出口] 内側壁がこれ未満なら加速を我慢
int TRIG_T=6;        // [回頭] 旋回がこの tick 数続く=深いコーナー
int DCF=24;          // [回頭] 1tick にこれ[mm]以上閉じ続ける=進入速度過多
int BURST=2, GAP=8;  // [回頭] ブレーキドリフトのデューティ (BRAKE 2 / 前進 8)
int RAMP=5;          // [TC] 1tick の踏み足し上限 (PWM)。+5/tick ≈ 0.29m/s² の加速要求で、
                     //      ウェット(grip0.5)の駆動上限 ≈0.86m/s² の1/3=横グリップを残して加速。
                     //      掃引実測 (5/6/8/10/12/15/20/∞): 5 だけが ドライ/ウェット/峠 全勝
                     //      (緩すぎても単コースは軌道カオスで悪化しうる。総合で判断)
int DEF_STYLE=2;     // [防御] 0=なし 1=ライン占有(狭路向き) 2=ドリフトウォール(広い直線向き)
int turnT; int prevTurn; int pC; int started; int fastT; int defT; int defOn;
int spdT; int escRec; int cur;

void setup() { RC_setup(); turnT=0; prevTurn=0; pC=0; started=0; fastT=0; defT=0; defOn=0; spdT=0; escRec=0; cur=0; }

void loop() {
  int L = sensor0.readRangeSingleMillimeters(); if (L < 0 || L > CONF) L = OPEN;  // 信頼区間外/範囲外=開放
  int C = sensor1.readRangeSingleMillimeters(); if (C < 0 || C > CONF) C = OPEN;
  int R = sensor2.readRangeSingleMillimeters(); if (R < 0 || R > CONF) R = OPEN;
  int dC = 0; if (started == 1) dC = C - pC; pC = C; started = 1;
  // 速度の目安: 前が開いていた直後だけ「速い」(低速の定常旋回ではレイ掃引で dC が
  // 急減して [回頭] が誤発火する — kin では無害だが dyn ではパワーオーバーで刺さる)
  if (C > D_MID) spdT = 10; else if (spdT > 0) spdT = spdT - 1;

  // [脱出] 行き止まり: 開いている側へ鼻先が向くよう逆ハンで後退 (壁前38mmでも生還)
  if (C < ESC) { if (L > R) RC_steer(RIGHT); else RC_steer(LEFT); RC_drive(REVERSE, 170); turnT = 0; escRec = 4; cur = 0; return; }
  // [脱出] 直後はタイヤを落ち着かせてから通常制御へ (dyn での前後往復スピンを断つ)
  if (escRec > 0) { escRec = escRec - 1; RC_steer(CENTER); RC_drive(FORWARD, 90); cur = 90; return; }

  // [防御] 後方に追走車 → 約3秒防御を維持 (横に並ばれ後方レイが見失っても解かない)
  int B = RC_read(BACK);
  if (B >= 0 && B < 650) defOn = 60; else if (defOn > 0) defOn = defOn - 1;
  defT = defT + 1;
  if (DEF_STYLE > 0 && defOn > 0) {
    if (C < 380) { if (L > R) RC_steer(LEFT); else RC_steer(RIGHT); RC_drive(FORWARD, 150); cur = 150; return; }
    if (R < 175) { RC_steer(LEFT); RC_drive(FORWARD, 120); cur = 120; return; }
    if (L < 175) { RC_steer(RIGHT); RC_drive(FORWARD, 120); cur = 120; return; }
    if (DEF_STYLE == 2) {  // ドリフトウォール: 振り出し→逆ハンの繰り返しでテールを流し車幅を塞ぐ
      int ph = defT % 24;
      if (ph < 6) { RC_steer(LEFT); RC_drive(FORWARD, 210); cur = 210; }
      else if (ph < 12) { RC_steer(RIGHT); RC_drive(FORWARD, 120); cur = 120; }
      else if (ph < 18) { RC_steer(RIGHT); RC_drive(FORWARD, 210); cur = 210; }
      else { RC_steer(LEFT); RC_drive(FORWARD, 120); cur = 120; }
      return;
    }
    RC_steer(CENTER); RC_drive(FORWARD, 150); cur = 150; return;   // ライン占有 (低速で前を塞ぐ)
  }

  // [通常] グリップ走行: 3段速度 + 旋回中は滑る手前で頭打ち + 出口で急に踏まない (旧版と同じ)
  int t = 1;
  if (C < D_TURN) { if (L > R) RC_steer(LEFT); else RC_steer(RIGHT); }
  else if (R < D_SIDE) RC_steer(LEFT);
  else if (L < D_SIDE) RC_steer(RIGHT);
  else { RC_steer(CENTER); t = 0; }
  int pwm = SLOW;
  if (C > D_OPEN) pwm = TOP;
  else if (C > D_MID) pwm = CRUISE;
  if (t == 1 && pwm > TCAP) pwm = TCAP;
  if (prevTurn == 1 && t == 0 && pwm > CRUISE) pwm = CRUISE;
  prevTurn = t;

  // [回頭] 深いコーナー & 速度過多が続く → ブレーキドリフト (減速しつつリアを流して回頭)
  if (t == 1 && C < D_TURN) turnT = turnT + 1; else turnT = 0;
  if (t == 1 && dC < 0 - DCF) fastT = fastT + 1; else fastT = 0;
  if (turnT >= TRIG_T && fastT >= 2 && spdT > 0) {
    int ph2 = (turnT - TRIG_T) % (BURST + GAP);
    if (ph2 < BURST) { RC_drive(BRAKE, 255); cur = cur - 40; if (cur < 60) cur = 60; return; }
    int rp = 205;
    if (rp > cur + RAMP) rp = cur + RAMP;
    cur = rp; RC_drive(FORWARD, rp); return;
  }

  // [出口] レイトアペックス: 前が開いても内側壁が近い間は CRUISE 止め + 外へ当て舵
  if (pwm > CRUISE) {
    if (R < GUARD && R < L) { RC_steer(LEFT); pwm = CRUISE; }
    else if (L < GUARD && L < R) { RC_steer(RIGHT); pwm = CRUISE; }
  }
  // [TC] 踏み足しはスルーレート制限 (アクセルを戻す側は即時)
  if (pwm > cur + RAMP) pwm = cur + RAMP;
  cur = pwm;
  RC_drive(FORWARD, pwm);
}

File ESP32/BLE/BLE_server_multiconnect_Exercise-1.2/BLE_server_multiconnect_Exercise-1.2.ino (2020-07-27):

#include <BLEDevice.h>
#include <BLEServer.h>
#include <BLEUtils.h>
#include <BLE2902.h>
#include <stdio.h>
#include <string>
#include <Wire.h>
#include <VL53L0X.h>

#include "RumiCar.h"

BLEServer* pServer = NULL;
BLECharacteristic* pCharacteristic = NULL;
bool deviceConnected = false;
bool oldDeviceConnected = false;
uint32_t value = 0;

#define SERVICE_UUID        "4fafc201-1fb5-459e-8fcc-c5c9c331914b"
#define CHARACTERISTIC_UUID "beb5483e-36e1-4688-b7f5-ea07361b26a8"


class MyServerCallbacks: public BLEServerCallbacks {
    void onConnect(BLEServer* pServer) {
      deviceConnected = true;
      BLEDevice::startAdvertising();
    };

    void onDisconnect(BLEServer* pServer) {
      deviceConnected = false;
    }
};

VL53L0X sensor0;
VL53L0X sensor1;
VL53L0X sensor2;

void setup()
{
  RC_setup();
// Create the BLE Device
  BLEDevice::init("RumiCar_ESP32_BLE");

  // Create the BLE Server
  pServer = BLEDevice::createServer();
  pServer->setCallbacks(new MyServerCallbacks());

  // Create the BLE Service
  BLEService *pService = pServer->createService(SERVICE_UUID);

  // Create a BLE Characteristic
  pCharacteristic = pService->createCharacteristic(
                      CHARACTERISTIC_UUID,
                      BLECharacteristic::PROPERTY_READ   |
                      BLECharacteristic::PROPERTY_WRITE  |
                      BLECharacteristic::PROPERTY_NOTIFY |
                      BLECharacteristic::PROPERTY_INDICATE
                    );

  // https://www.bluetooth.com/specifications/gatt/viewer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
  // Create a BLE Descriptor
  pCharacteristic->addDescriptor(new BLE2902());

  // Start the service
  pService->start();

  // Start advertising
  BLEAdvertising *pAdvertising = BLEDevice::getAdvertising();
  pAdvertising->addServiceUUID(SERVICE_UUID);
  pAdvertising->setScanResponse(false);
  pAdvertising->setMinPreferred(0x0);  // set value to 0x00 to not advertise this parameter
  BLEDevice::startAdvertising();
  Serial.println("Waiting a client connection to notify...");  
}

void loop()
{

char buff[100];
sprintf(buff, "Sensor0:%d,Sensor1:%d,Sensor2:%d" ,
              sensor0.readRangeSingleMillimeters(),
              sensor1.readRangeSingleMillimeters(),
              sensor2.readRangeSingleMillimeters()
              );   
    // notify changed value
    if (deviceConnected) {
        pCharacteristic->setValue(buff);
        pCharacteristic->notify();
value=100;
        delay(10); // bluetooth stack will go into congestion, if too many packets are sent, in 6 hours test i was able to go as low as 3ms
    }
    // disconnecting
    if (!deviceConnected && oldDeviceConnected) {
        delay(500); // give the bluetooth stack the chance to get things ready
        pServer->startAdvertising(); // restart advertising
        Serial.println("start advertising");
        oldDeviceConnected = deviceConnected;
    }
    // connecting
    if (deviceConnected && !oldDeviceConnected) {
        // do stuff here on connecting
        oldDeviceConnected = deviceConnected;
    }



}

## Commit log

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2020-05-25 update source code for VL53L0X
    changing controll of shutdown pins to prevent excessive voltage
    [RumiCar.py]
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2022-08-12 fix 3 sensors output
    [RumiCar.py]
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2023-12-24 CM PCB data added.
    [RumiCarGen3-CM5.brd, RumiCarGen3-CM5.sch]
2024-02-17 Add Gen3-Sensor3 PCB data.
    [RumiCarGen3-Sensor3.brd, RumiCarGen3-Sensor3.sch]
2024-02-18 Add Gen3-Sensor4(I2C) PCB data.
    [RumiCarGen3-Sensor4.brd, RumiCarGen3-Sensor4.sch]
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2024-03-29 Rename CM PCB/RumiCarGen3-CM5.brd to CM PCB/Ohe大栄 san CM/RumiCarGen3-CM5.brd
    [RumiCarGen3-CM5.brd]
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2024-03-29 Rename CM PCB/RumiCarGen3-CM5.sch to CM PCB/Ohe大栄 san CM/RumiCarGen3-CM5.sch
    [RumiCarGen3-CM5.sch]
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2025-06-22 Rename Front_StearParts_for_offroad.step to Front axle parts/Front_StearParts_for_offroad.step
    [Front_StearParts_for_offroad.step]
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2026-05-03 Update README with library manager announcement
    Added announcement about RumiCar library availability in Arduino Library Manager and future removal of old libraries.
2026-05-03 Revise README for RumiCar Library installation instructions
    Updated README to reflect the RumiCar library's registration in the Arduino Library Manager and recommended installation method.
2026-05-03 Clarify install steps and reposition library repo link
    Restructures the library installation announcement to reduce learner confusion.
    Problem: The previous wording placed the RumiCar-lib repository link inline with the install instructions, which could lead learners to navigate there instead of completing the install entirely within Arduino IDE.
    Changes (both Japanese and English):
    - Added an explicit heading 'Installation steps (all done inside Arduino IDE)' to make it clear the entire process happens in the IDE
    - Replaced the single inline paragraph with a numbered 4-step procedure
    - Added step 4 covering the VL53L0X 'Install all' dependency prompt
    - Moved the RumiCar-lib reposi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
2026-05-03 Clarify install steps in Libraries/README.md
    Applies the same install-instruction improvements as the top-level README (commit 2187288) to ArduinoAndESP32/Libraries/README.md, so the messaging is consistent regardless of which README a learner lands on first.
    Changes (both Japanese and English Important callout):
    - Added an explicit heading 'Installation steps (all done inside Arduino IDE)' to make clear the entire process happens in the IDE
    - Moved the RumiCar-lib repository link to its own line, labeled 'Library source code (for reference)' to p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
2026-06-10 Add Fable Racing Line: per-car-type optimized driving programs (programs/)
    6 driving programs, one tuned per car type (FF/FR/4WD × normal/drift), that draw
    out each car's physical characteristics. Arduino C++ format (runs on real RumiCar).
    - Quattro Blitz (4WD), Apex Hunter (FR), Steady Nose (FF),
    Grip Reaper (drift FR), Rally Tamer (drift 4WD), Lift Whisper (drift FF)
    - Adaptive gap-follower: 3-stage speed by front distance + per-car corner
    throttle-cap (TCAP) to tame oversteer. Differences are constants only, so they
    are easy to read-compare.
    - programs/index.json catalog, programs/README.md with strategy table.
    The simulator auto-loads the matching program when a car type is sele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
    [normal_awd-quattro-blitz.ino, normal_ff-steady-nose.ino, normal_fr-apex-hunter.ino]
2026-06-10 Fable Racing Line: add per-program design rationale comments
    Each .ino now embeds a 「なぜこの設定にしたか」 block explaining, per car type,
    which physical characteristic (config.js DRIVE params) the constants exploit and
    why — to help humans understand the intent and as an educational aid.
2026-06-10 programs/README: fix mangled table + add real-car porting & tuning guide
    - Strategy column was accidentally filled with full program source; now shows the
    short one-line strategy per program.
    - Add a constants reference table and a 「実車 RumiCar で走らせる・改変する人へ」
    section: sim-to-real differences, a safe step-by-step tuning order (slow first,
    fit D_* to real sensors, raise PWM gradually, measure the real drift threshold),
    and symptom-based fixes (over-rotation / understeer / weaving). Educational aid
    for people who download and modify these on real hardware.
2026-06-10 Add programs/community for user-submitted driving programs
    New folder where users save their edited programs under a new name (PR-based,
    no overwrite). The simulator lists these under 「🌐 みんなの投稿」 in each car's
    program menu so anyone can pick and reuse them. Includes a README (how to submit)
    and one example program (Balanced Cruiser).
2026-06-10 docs: surface the simulator, driving-logic guide, and community sharing
    - Top README: add a "RumiCar Simulator" entry under フォルダの説明 linking to the
    simulator and the programs/ and courses/ folders (where the Fable Racing Line
    driving-logic explanation and real-car tuning guide live).
    - programs/README: update the simulator usage section for the new features
    (auto-load per car type, cross-car comparison, 🌐 community programs:
    edit → run → save under a new name → reuse).
2026-06-11 Add experimental Drift Striker program (technique demo)
    A situation-branching drift program combining the extended physics: continuous
    drift onset, counter-steer stabilization, and sensor-derivative perception
    (front closing rate). Provokes a tail-slide only on very tight (hairpin) corners
    and catches it with opposite lock when the corner opens.
    Honest note in the header: with RumiCar's 3-value steering at 20Hz, provoked
    drift does NOT beat pure grip in the simulator (grip is the robust optimum).
    Kept as an educational demo of the techniques; on a real car with finer steering
    it may win. Includes tuning hints.
2026-06-11 Re-tune 4WD programs (Quattro Blitz / Rally Tamer) for the new weight model
    With mass added to the physics, 4WD (heaviest) understeers a bit more, so the two
    4WD programs now brake slightly earlier and cap corner speed lower to avoid running
    wide. Restores their completion rate.
    [normal_awd-quattro-blitz.ino]
2026-06-11 Add 3 touge (downhill point-to-point) courses to the catalog
    峠①ヤビツ風 (緩い下り) / 峠②秋名風 (タイト下り) / 峠③椿風 (高速下り).
    New kind:'touge' — start at the top, goal at the bottom, with downhill gravity.
    The simulator measures start→goal time (not laps). Demonstrates how car weight
    and drive type trade off on a mountain pass (light RWD on tight, heavy 4WD on fast).
2026-06-11 Fable Racing Line v2: per-car logic that draws out each car's character
    Rewrote the 6 programs so each embodies the LOGIC that exploits its car (not just
    header constants), ordered for learning (simple → characteristic):
    Lv1 FR (baseline) → Lv2 4WD (dC exit-throttle) → Lv3 FF (lift while steering) →
    Lv4 drift FR (limit discipline) → Lv5 drift 4WD → Lv6 drift FF (rate-limited lift).
    Each .ino header explains why the logic is needed and what it targets. README now
    groups them by level and calls out which cars need only constant tuning vs distinct
    logic. All run on real RumiCar (Arduino C++).
    [normal_awd-quattro-blitz.ino, normal_ff-steady-nose.ino, normal_fr-apex-hunter.ino]
2026-06-11 Add tactical programs: Blocker (area denial) and Overtaker (passing)
    Measured in 2-car races (cars treat each other as obstacles, like the sim):
    - Blocker: holding the opponent's line at LOW speed is the strongest block — a naive
    follower is pinned (3-7% of free distance) on any course; even an Overtaker can't pass
    on a narrow course. Flashy drift/weaving backfires (opens the line). On wide courses
    the block becomes "force them onto the slow outside line".
    - Overtaker: exploits the lateral gap past a leading car. Passes on wide courses but not
    narrow ones — course width decides attack vs defence.
    Each .ino documents the WHY. Educational point: in specific conditions a slower car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
    [blocker-area-denial.ino]
2026-06-11 Add Blocker v2 (get-ahead-then-defend) and Racing Line (speed profile) + numbers
    - blocker-v2-getahead.ino: 2-phase tactic. Measured: with a pace edge on a narrow
    course it gets ahead and bottles the rival to 30% of free distance; at equal pace it
    can't pass and crashes trying. Confirms "getting ahead is the risky precondition".
    - racing-line-speed.ino: geometric out-in-out is impossible with 3-value reactive
    steering (0/10 finish); the speed-profile version is 98.8% of the wall-follower
    (faster only on fast flowing courses). Reactive control → wall-following is near-optimal.
    README: added a "which car/strategy wins in which condition" summary table with numbers.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
    [blocker-v2-getahead.ino]
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2026-06-11 Add wet courses + fictional long-winding touge (varied elevation) to catalog
    - 2 wet (low-grip) courses, 3 fictional long-winding touge with different elevations
    (gentle 25m / mid 45m / steep 75m), and elevation (elev) on the switchback touge.
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2026-06-11 Add purpose-driven drift programs: Drift Wall (blocking) and Drift Showtime (show)
    Honest finding (measured): with 3-value steering, deliberate drift can't beat grip on
    lap speed (30-course sweep: completion 27->24, less distance; touge/super-hairpin no
    better). Grip-based Fable Racing Line remains fastest. So drift's real value is elsewhere:
    - drift-wall-blocker.ino: occupy the line with the car's width. Where a simple slow block
    is passed (Speedway/Bottleneck 99%), Drift Wall pins the overtaker to 2-4%. Course-
    dependent (over-rotates on wide Oval) — complementary to simple blocking.
    - drift-showtime.ino: entertainment. Continuous donuts / figure-8 in the new open
    "Drift Plaza (sho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
2026-07-30 courses/programs を正本の現行世代へ更新し、cars/community を開通
    シミュレータ正本 (RumiCar-group/RumiCar-Simulator) の
    gen_course_files.mjs / gen_program_files.mjs から再生成して反映した。
    courses は v3.40.0 以前の世代で止まっており、多言語表示・難易度・入門バッジが
    機能しない状態だった。
    courses:
    - 競技グラウンド/競技サーキット (フルスケール) の2コースを追加。
    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
2026-08-02 courses/programs: 実在サーキット名・登録商標語を汎用名へ置換
    権利クリアランスのため、実在サーキット名を模した20コース名（鈴鹿風/モナコ風/
    モンツァ 等）を記述的な名称へ改名し、登録商標 "Quattro"（Audi AG）を含む
    プログラム名 "Quattro Blitz" を "Traction Blitz" へ変更した。
    - courses/*.json: 20ファイルをリネーム（内容は名称・説明文のみ変更、レイアウト
    ジオメトリは無改変）。courses/index.json を追従更新。
    - programs/normal_awd-quattro-blitz*.ino: normal_awd-traction-blitz*.ino へ
    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
2026-08-02 ArduinoAndESP32/Libraries: 旧ローカル版ライブラリを削除 (Library Manager / RumiCar-lib へ一本化)
    RumiCar ライブラリは Arduino 公式の Library Manager に登録され (RumiCar v0.3.0・
    repository = RumiCar-group/RumiCar-lib)、README で予告していたとおり、この
    ディレクトリのローカル版を削除しました。
    削除:
    - ArduinoAndESP32/Libraries/RumiCar.zip
    - ArduinoAndESP32/Libraries/RumiCar/{RumiCar.cpp,RumiCar.h}
    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
2026-08-02 release ワークフロー: 旧ライブラリの zip 生成/添付を削除
    ArduinoAndESP32/Libraries/RumiCar/ を削除したため、そこから zip を作るステップは
    実行できません (作れても古いライブラリを配ってしまいます)。ライブラリのリリースは
    後継の RumiCar-lib 側で行う想定です。本ワークフローは教材リポジトリのタグ付け/
    リリース作成としては従来どおり動作します。
2026-08-07 docs: replace outdated "Readme English.md" with a full README.en.md
    The old English readme (89 lines) predated the simulator, programs/ and
    courses/ sections and had a space in its filename. README.en.md is a full
    translation of the current Japanese README (announcement, all exercises,
    folder guide, simulator, links), with cross-language links at the top of
    both files. Original translation assistance by Emi Ito is credited.
    Both READMEs now state that issues and PRs are welcome in English or
    Japanese.
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2026-09-04 community: 投稿一覧の index.json を追加し自動更新する
    シミュレータ (RumiCar-group/RumiCar-Simulator) は投稿一覧を GitHub contents
    API で取得している。未認証の API は IP あたり 60 回/時で、1 回起動するごとに
    4 回消費するため、実測では 15 回開いた時点で上限に達する。教室のように 1 本の
    回線を大勢で共有すると数回ずつ開いただけで打ち止めになり、投稿コース・
    プログラム・車種が「取得できませんでした」になっていた (走行は止まらない設計)。
    raw.githubusercontent.com にはこの制限が無い (応答にレート制限ヘッダが
    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
2026-09-11 courses/community: 利用者投稿コース「富士スピードウェイ」を追加
    シミュレータの「🌐 GitHubで共有」が URL 長超過で開けないため (共有 URL は実コースで
    250,233 文字・GitHub の受理上限は実測 約 6,600 文字)、投稿者から JSON を受け取って
    運営側で代理登録した。投稿データは無改変。
    sha256: 21674d0c1cb41f0e21f2e420dec22f309b9cd451df50bdc7949f0896cddb9984
    壁 366 本 / 枠 18.36 x 18.71 m / スタート地点の廊下幅 0.300 m。
    本物のオラクル (fitsAllCars / freeSpawn / checkCollision / minClearance) で実測:
    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
2026-09-12 courses: 投稿手順を新方式（ダウンロード → アップロード画面）へ更新
    シミュレータの「🌐 GitHubで共有」が、コースの中身を URL に載せる方式では
    投稿できなかった（github.com の受理上限 約6,600文字に対し実コースは数万〜数十万文字）。
    中身を URL から外し、ファイルをダウンロードしてアップロード画面に置く方式へ変更したので
    README の手順を実態に合わせる。ファイル名が一覧の表示名になることも明記。
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2026-10-17 README: Exercise の入手先をライブラリのスケッチ例に更新、Hands-on text へのリンク切れを修正
    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

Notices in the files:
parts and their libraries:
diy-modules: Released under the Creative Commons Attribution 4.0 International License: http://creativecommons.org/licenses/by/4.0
